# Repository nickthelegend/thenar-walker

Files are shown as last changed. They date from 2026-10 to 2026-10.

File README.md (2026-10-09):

# Thenar Walker — RoboReach 2026-27 robot

A 12 V four-wheel drive base for the **[thenar-arms](https://github.com/nickthelegend/thenar-arms)
MG996R follower arm**, built for [Techfest IIT Bombay RoboReach](https://techfest.org/competitions/roboreach).
The arm is unchanged; it is driven wirelessly by the thenar-arms **encoder leader** plus a joystick.
Everything is native SolidWorks 2026, generated by scripts so it can be rebuilt after any change.

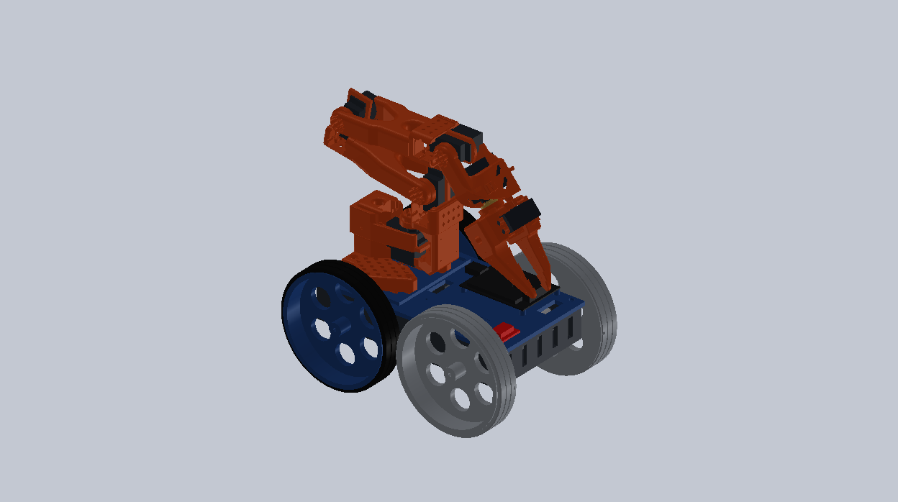
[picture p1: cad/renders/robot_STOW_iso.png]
Robot in the start pose


| | |
|---|---|
| Start size (STOW) | **293.7 × 196.0 × 292.9 mm** (rule 300 × 200 × 300) |
| Ground clearance | **57 mm** (rule ≥ 50) |
| Object centre at REACH_450 | **449.6 mm** in SolidWorks (rule: object centred at 450) |
| Mass | 2.37 kg (CAD) |
| Drive | 4 × 25GA-370 **12 V 60 RPM** (103:1), Ø140 printed wheels (one-piece PETG front, TPU-tyred rear), skid steer, ~0.34 m/s |
| Power | 3S LiPo 2200 mAh (12.6 V max, rule ≤ 24 V), 15 A fuse, 30 A kill switch |
| Link | ESP32 Wi-Fi AP `<TeamName>_TF`, HMAC-SHA256 signed commands, disconnect HOLD |

### Current build (October 2026) — what the team is actually building

The parts bought locally differ from the original design above, and the printable files follow the real parts:

| | |
|---|---|
| Motors | 4 × 370 plastic-gearbox 12 V ~100 RPM (gearbox Ø37.5, M8 × 13 collar + 13 mm nut, Ø6 round shaft). Bottle test passed (≥ ~5.2 kg·cm); simulated at 100 rpm: passes from 4.9 kg·cm |
| Chassis tub | **tub v2** — `cad/tools/tub_v2.py` (mesh CAD, 11/11 fit checks in `cad/evidence/tub_v2_checks.json`): M8 collar through 13 mm wall pads, nut pockets, walls to 100 mm, engraved **THENAR.IO** / **THENARLABS**. Ground clearance 51.25 mm, 294 × 196 mm |
| Deck | 3 mm wooden board cut to 250 × 138 — template `docs/wood_deck/` |
| Motor driver | Cytron **MDD10A** (one board, PWM + DIR), on the deck top |
| Wheels | 6 mm-bore versions (plate 4b), flat TPU tyre strips (plates 5F / 5G) |
| Assembly film | **[Watch / download the 4-minute assembly film](https://github.com/nickthelegend/thenar-walker/releases/tag/v1)** — every part and every connection, built from this CAD (`videos/thenar-assembly`) |

The SolidWorks assembly and `docs/VERIFICATION.md` still show the original 25 mm-motor tub; resync them when SolidWorks is available.

Full measured results: **[docs/VERIFICATION.md](docs/VERIFICATION.md)** (SolidWorks) and
**[docs/SIMULATION.md](docs/SIMULATION.md)** (physics: it drives the course and picks things up).

### It runs the course (MuJoCo physics + the real firmware logic in the loop)

| Scenario | Result |
|---|---|
| A — pick 50 mm cube → 15° ramp → bridge → ramp down → 4 speed breakers → place in the 80 mm square | **PASS 7/7** · [video](sim/out/mission_A.mp4) |
| B — same, with a 1.5 s Wi-Fi drop on the bridge + 75 forged/replayed packets | **PASS 12/12** — stops, arm freezes, gripper holds, attacks rejected · [video](sim/out/mission_B.mp4) |
| C — Downy: 60 mm cube off the 400 mm pole, arc turns like a driver, place in its square | **PASS 5/5** · [video](sim/out/mission_C.mp4) · [spin-in-place version](sim/out/mission_C_spin.mp4) |

| | |
|---|---|
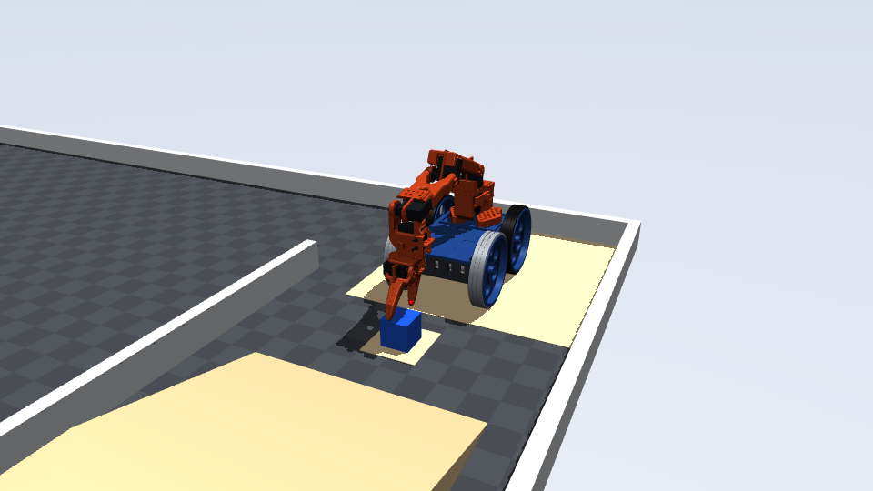
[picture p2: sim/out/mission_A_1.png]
pick
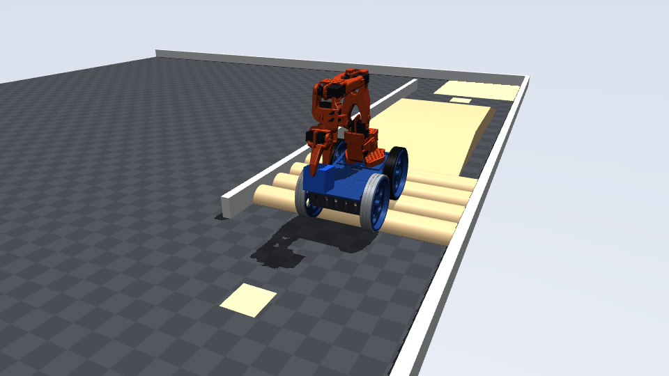
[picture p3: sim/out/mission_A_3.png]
|  |  |

## Contents

| Path | What |
|---|---|
| `cad/assemblies/Thenar_Walker.SLDASM` | Robot. Configurations **STOW**, HOME, REACH_450, PICK_FLOOR, DRIVE_ONLY |
| `cad/arena/RoboReach_Arena.SLDASM` | 3 × 3 m arena with all game objects, robot parked at the start |
| `cad/arena/Terrain_Check.SLDASM` | Robot on the ramp / bridge / speed breakers (last checked pose) |
| `cad/parts/` | Robot parts (RR-xx printed, P-xx purchased envelopes) |
| `cad/print/` | **Ready Bambu P1S plates** (5 × 3MF, no supports) — see [cad/print/PRINT.md](cad/print/PRINT.md) |
| `cad/stl/` | Single-part STLs |
| `cad/vendor/thenar-arms/` | thenar-arms follower master + parts (Apache-2.0, SO-ARM100 derived) with the four pose configurations added |
| `cad/tools/` | Python (pywin32) scripts that build and verify everything in SolidWorks |
| `analysis/` | URDF kinematics, collision-aware stow search, gripper opening, drive sizing |
| `sim/` | MuJoCo model of robot + arena, firmware-in-the-loop bridge, mission scenarios, videos (`sim/out/`) |
| `firmware/` | Robot + controller ESP32 sketches, shared `ThenarLink` library, host unit tests |
| `mobile/` | **Thenar Remote** Expo app (Android): drive + arm + Bluetooth game controller over the robot Wi-Fi — see [mobile/README.md](mobile/README.md) |
| `docs/calibrator/` | Browser arm calibrator (Web Serial) |
| `docs/` | [BOM](docs/BOM.md) · [Wiring](docs/WIRING.md) · [Build guide](docs/ASSEMBLY.md) · [Design notes](docs/DESIGN.md) · [Verification](docs/VERIFICATION.md) · [Simulation](docs/SIMULATION.md) |

| | |
|---|---|
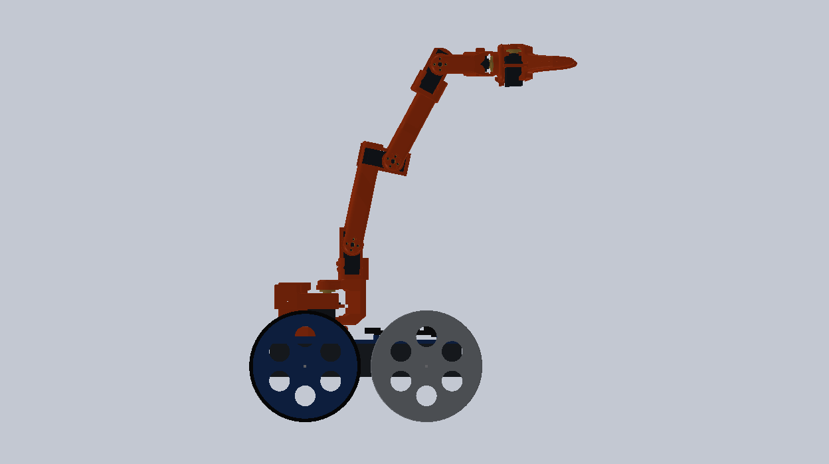
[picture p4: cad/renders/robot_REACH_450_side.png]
reach
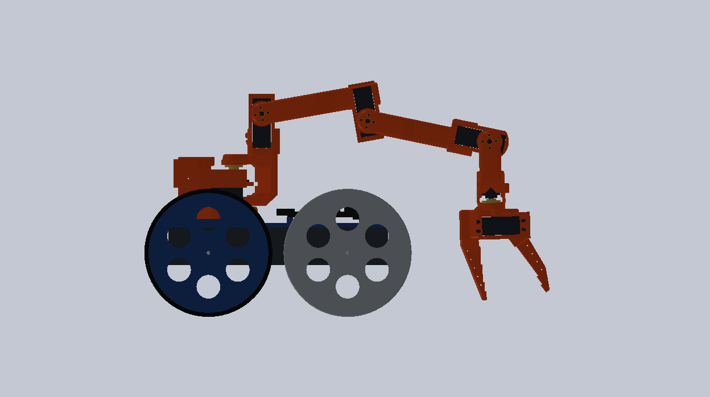
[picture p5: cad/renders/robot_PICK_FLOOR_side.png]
floor pick
|  |  |
| REACH_450 — object centred at 449.6 mm | PICK_FLOOR — 50 mm cube on the floor |
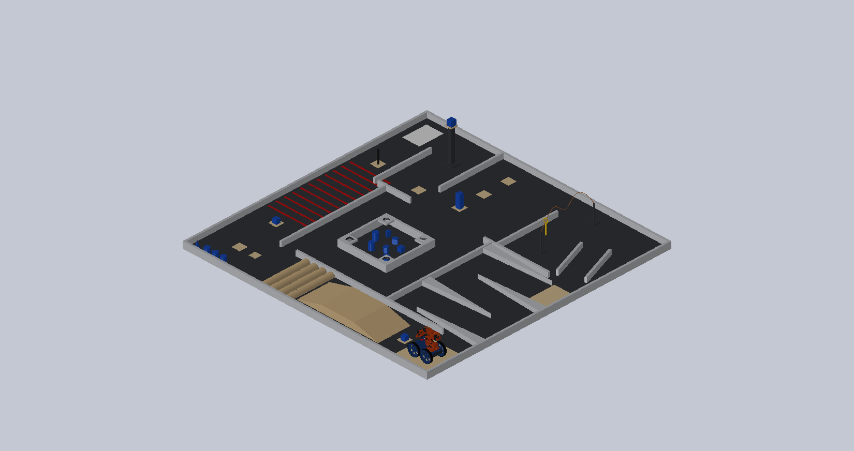
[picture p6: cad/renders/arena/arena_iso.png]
arena
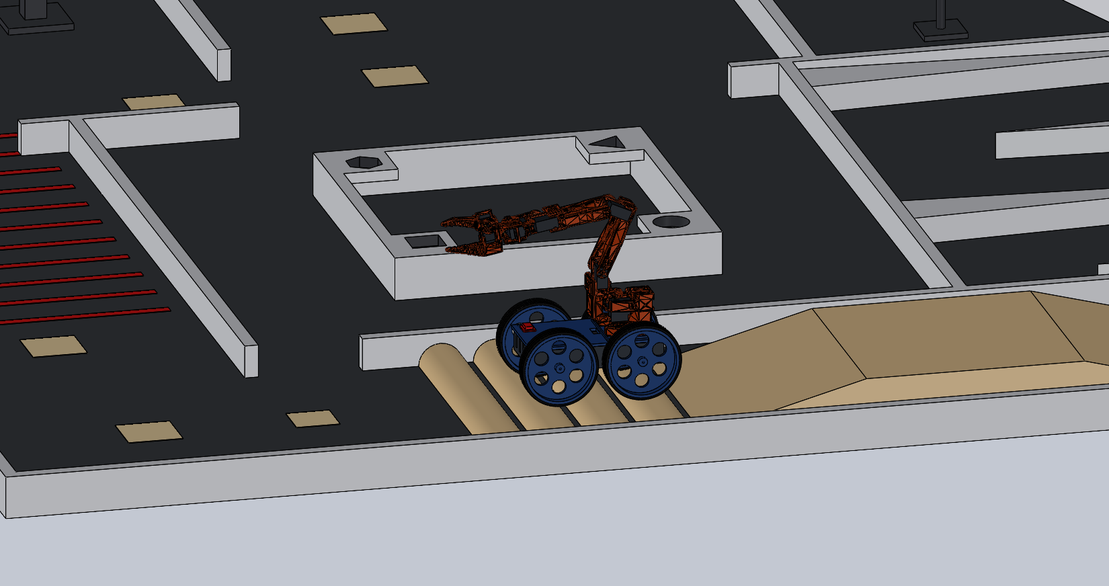
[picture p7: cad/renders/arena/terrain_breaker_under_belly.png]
|  |  |
| Arena (rulebook layout, ±10 %) | Over the 40 mm speed breakers |

## Rebuild / re-verify (SolidWorks 2026 must be running)

```
python cad/tools/build_parts.py          # all parts + STL
python cad/tools/make_plates.py          # P1S print plates (cad/print)
python cad/tools/prepare_arm.py          # arm pose configurations, cross-checked vs URDF
python cad/tools/build_robot.py          # robot assembly
python cad/tools/verify_robot.py         # rule checks (start box, clearance, reach, interference, stability)
python cad/tools/build_arena.py          # arena parts
python cad/tools/build_arena_asm.py      # arena assembly + terrain interference checks
python cad/tools/render_robot.py         # renders
python cad/tools/make_report.py          # docs/VERIFICATION.md
```

The scripts only open and close their own documents; other SolidWorks work stays open.
Python: `pywin32 numpy trimesh scipy python-fcl rtree`.

## Simulation

```
python sim/build_model.py            # MuJoCo model from the CAD numbers
python sim/run_mission.py A          # also B, C   (add --novideo to skip rendering)
python sim/turn_study.py             # skid-steer turning study (tyres / motors / spin vs arc)
python sim/make_sim_report.py        # docs/SIMULATION.md
```
Needs `mujoco imageio imageio-ffmpeg` and `sim/fw_bridge.exe` (build: `g++ -std=gnu++14 -O2 -static -o sim/fw_bridge.exe sim/fw_bridge.cpp`).

## Firmware

```
python firmware/tools/new_key.py "Your Team Name"
powershell -File firmware/tests/run_tests.ps1          # 39 host checks: SHA-256/HMAC, auth, replay, failsafe, turning
powershell -File firmware/tools/compile_firmware.ps1   # both ESP32 sketches
```

## Status

CAD, kinematics, collisions, obstacle clearance, the full course in physics simulation and the firmware
logic are verified in software. Nothing has been built or powered yet: check purchased parts against the
CAD, measure real tyre/gripper friction, calibrate the servos, and run the failsafe test in
`docs/ASSEMBLY.md` before the event.

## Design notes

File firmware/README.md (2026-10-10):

# Firmware

| Sketch | Board | Role |
|---|---|---|
| `thenar_walker_bot/` | ESP32 on the robot | Wi-Fi AP `<Team>_TF`, 4 × 12 V motors (1 × Cytron MDD10A, PWM + DIR), 6 × MG996R (PCA9685), failsafe |
| `thenar_phone/` | ESP32-S3 on the robot | **Phone control**: Wi-Fi AP `<Team>_TF`, page at http://192.168.4.1, WebSocket for low latency, calibrator over USB |
| `arm_calibration/` | ESP32-S3 on the robot | Serial bridge for the browser arm calibrator (`docs/calibrator/`), saves the calibration to NVS |
| `thenar_walker_controller/` | ESP32 in the thenar-arms L1 leader | Reads the 6 AS5600 joints + joystick, sends signed commands at 50 Hz |
| `libraries/ThenarLink/` | both + host tests | SHA-256/HMAC, packet format, replay gate, robot state machine, drive mixing |

Everything safety-relevant is in `libraries/ThenarLink/src/tw_robot.h` and is unit-tested on the PC
(`tests/run_tests.ps1`, uses PlatformIO's bundled MinGW g++). The sketches are thin hardware glue.

States: **DISARMED** (boot, servo PWM off) → **ACTIVE** (leader within 6° of STOW + ENABLE) ⇄
**HOLD** (link silent 250 ms / ENABLE off / bad target / encoder fault: wheels 0, arm frozen,
servo PWM kept on so the gripper holds). HOLD → ACTIVE only on a new authenticated command, with
a 45°/s catch-up limit for 1.5 s.

Driving: throttle is scaled 35/65/100 % by the SPEED button; turning in place uses its own 50/75/100 %
scale with a 35 % breakaway floor (`TURN_SCALE`, `SPIN_MIN`) — tuned for PETG front / TPU rear tyres
(sim/turn_study.py).

Credentials: `python tools/new_key.py "Team Name"` writes `libraries/ThenarLink/src/team_config.h`
(git-ignored). Flash both boards after generating it. The example config compiles with a warning
so you notice.

Servo calibration values live in `thenar_walker_bot/calibration.h` (same meaning as thenar-arms).
Until `FOLLOWER_CALIBRATED = true` the arm stays unpowered while the wheels work.

## Phone control (`thenar_phone`) — the way to drive the robot

The robot is a Wi-Fi hotspot `<Team>_TF`. Join it with the phone (turn mobile data off), open **http://192.168.4.1**:
joystick for the wheels, Slow/Mid/Fast, STOP, and per joint a slider, hold-to-move − / + buttons and ON/OFF.

Low latency: after the page loads, everything goes over one WebSocket (port 81) that stays open. A touch is sent the
moment it happens (once per screen frame at most), Nagle is off on both ends, the ESP32's Wi-Fi power save is off,
and the control loop runs at 100 Hz. The top bar shows the measured round trip in ms.

Safety: the phone sends at least every 40 ms; 300 ms of silence (tab closed, screen off, Wi-Fi lost) stops the wheels
and the hold buttons, and the arm holds where it is. Calibration: `docs/calibrator` talks to this same firmware over USB.

```
arduino-cli compile --fqbn esp32:esp32:esp32s3 --libraries firmware/libraries -u -p COM5 firmware/thenar_phone
```

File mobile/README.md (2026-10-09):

# Thenar Remote (Expo app)

Android app that drives the Thenar Walker: wheels, the 6-joint arm, and a Bluetooth game controller paired to the
phone. It talks to the robot firmware [`firmware/thenar_phone`](../firmware/thenar_phone) over the robot's own Wi-Fi
(`ThenarWalker_TF`, WPA2) at `http://192.168.4.1`.

## What it does that the robot's web page can't
- **Reads the game controller natively.** Any controller Android accepts (Switch-style, Xbox, PS, 8BitDo...) — no
  Chrome flag, no BLE limit. Buttons are consumed, so B doesn't act as Back.
- **Joins and pins the robot Wi-Fi.** Android normally sends traffic over mobile data when the Wi-Fi has no internet.
  The app binds itself to the robot network (⚙ → *Join robot Wi-Fi* asks Android once, Android 10+).
- Keeps the screen on, remembers the Wi-Fi password in the phone's secure storage.

## Controls
Screen: joystick (let go = stop), Slow/Mid/Fast, STOP, a slider + ±1/±5° + ON/OFF per joint, gripper open/close.

| Controller | Does |
|---|---|
| Left stick | drive |
| Right stick | J1 base pan (x), J2 shoulder (y) |
| D-pad ↑↓ / ←→ | J3 elbow / J5 wrist roll |
| Y / A | J4 wrist flex up / down |
| L2 / R2 | gripper open / close |
| L1 / R1 | speed down / up |
| **B** | **STOP** (wheels stay stopped until the stick is centred) |
| X | precision arm (20°/s instead of 60°/s) |
| hold START 1 s | arm ON — every calibrated joint (support the arm: joints jump to their target) |
| hold SELECT 1 s | arm limp |

Safety lives in the robot, not the phone: app silent for 0.5 s → wheels stop and the arm holds; the robot clamps every
angle to the calibrated safe ends; uncalibrated joints can't be switched on; the KCD4 kill switch cuts power.

## Install
Copy `Thenar_Remote.apk` to the phone and open it (allow "install unknown apps" for your file manager once).
Or with USB debugging: `adb install -r Thenar_Remote.apk`.

## Develop
```
npm install
npm test                 # end-to-end: app logic + gamepad mapping against a robot simulator (test/mock_robot.py)
npm run typecheck && npx expo lint
npm run mock             # robot simulator on 127.0.0.1:8793
npx expo start --web     # web build; ⚙ → robot address 127.0.0.1:8793 to drive the simulator
```
Build the APK (needs JDK 17 + Android SDK; the native module means Expo Go can't run it):
```
npx expo prebuild -p android
cd android && gradlew assembleRelease -PreactNativeArchitectures=arm64-v8a
# -> android/app/build/outputs/apk/release/app-release.apk
```

## Layout
- `App.tsx` — the screen
- `src/robot.ts` — robot link (protocol, 10 Hz exchange, merge with the robot's own state)
- `src/pad.ts` — controller layout (same as the firmware's Bluepad32 mapping)
- `modules/thenar-native` — local Expo module (Kotlin): gamepad events + Wi-Fi binding; web fallback uses the
  browser Gamepad API
- `test/` — `mock_robot.py` (firmware rules: slew, clamps, STOP latch, 0.5 s failsafe) and `e2e.test.ts`

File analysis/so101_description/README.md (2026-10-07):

# SO101 MG996R R3 description

Engineering prototype, not physically tested or payload rated. Generated from the checked SolidWorks reconstruction and measured component transforms.

Run `colcon build --packages-select so101_description`, source the install setup, then `ros2 launch so101_description display.launch.py` on a ROS 2 installation. ROS 2 GUI/build validation is not available in this Windows task environment; standalone Xacro/XML/kinematic validation is separate.

Six revolute joints include the directly driven moving jaw. The base frame retains the source convention. Add a +0.0024 m world-Z placement to match the SolidWorks tabletop scene. Mesh coordinates and URDF origins are metres.

No physical inertial guesses are included. Effort=0 deliberately grants no effort authority; it is not a servo rating. Velocity=10 deg/s is the existing firmware command slew ceiling. This geometry package does not provide a hardware driver, measured feedback, payload rating or physical-dynamics validation.

The servo collision envelope uses its exact source boxes and cylinders. Other collision meshes preserve the CAD solids. No convex print proxy has been accepted; do not let a physics importer silently replace each concave link with one convex hull. Shaft/horn spline engagement is intentional in the source. J2 and J3 maximum-at-other-joints-zero poses penetrate the tabletop.

Original project asset licensing still applies; no new license rights are asserted by this generated package.

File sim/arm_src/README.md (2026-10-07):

# MuJoCo handoff: kinematics checked, physical simulation blocked

`so101_import_test.urdf` was loaded in MuJoCo 3.14.0 and all 28 canonical link-pose comparisons passed. The importer silently inferred masses; these were rejected as physical robot properties. No dynamics steps were accepted or reported as physical verification.

`so101.xml` preserves the six-joint structural tree and visuals. It deliberately sets `inertiafromgeom="false"` and contains no fabricated inertials. MuJoCo must reject loading it until measured/supported link mass, COM and inertia are entered. Visual geoms have contacts disabled; validated convex contact proxies remain outstanding. This file is a structural template, not a runnable physical model.

The exact CAD collision meshes and raw intentional shaft/horn overlaps are retained in the ROS package. A 0.1 mm convex decomposition trial became impractically fragmented and was abandoned without accepting geometry. Do not replace each concave print with one convex hull. Damping, friction, armature, contact properties and actuator dynamics are unknown; future values must be separately labelled tuning assumptions.

Run `../../solidworks/tools/test_mujoco_urdf_import.py` from the project Python environment for the reproducible forward-kinematic inspection. Evidence: `../../verification/mujoco_urdf_import.json`.

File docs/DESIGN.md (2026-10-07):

# Design notes — Thenar Walker

A 12 V four-wheel skid-steer base that carries the **thenar-arms MG996R follower R3** unchanged,
teleoperated by the **thenar-arms L1 encoder leader** plus a thumb joystick, for Techfest 2026-27
RoboReach. Every number below is produced by a script in this repo; `docs/VERIFICATION.md` holds the
measured results.

## Rules that set the geometry

| Rule (RoboReach PS) | Consequence |
|---|---|
| Fits 300 L × 200 W × 300 H at the start | Arm must fold; base ≤ 300 × 200 including wheels |
| Arm grasps an object centred at 450 mm with the bot on the ground | Arm base height + reach |
| Ground clearance ≥ 50 mm (lowest point to ground) | Big wheels; motors on the axle line stay above 50 mm |
| Wheels in continuous contact | No legs/tracks over obstacles; Ø140 wheels roll over 40 mm breakers |
| ≤ 24 V, on-board battery, secured battery, kill switch | 3S LiPo (12.6 V max), printed battery cage, 30 A rocker in series |
| Wi-Fi/BT, SSID `TeamName_TF`, authentication, failsafe on disconnect | ESP32 AP + HMAC-signed UDP + HOLD state (see WIRING.md) |
| Mechanical gripper only | thenar-arms jaw gripper, no adhesive/magnet/suction |

## Layout (robot frame: X forward, Y left, Z up, origin on the ground at the chassis centre)

* **Wheels:** Ø140 (printed PETG hub + TPU tyre), 28 wide, centres at x = ±76, y = ±84.
  Overall 293.7 × 196 mm. A Ø140 wheel puts the axle at 70 mm, so a Ø25 JGA25 motor mounted
  coaxially bottoms out at 57.5 mm — above the 50 mm clearance rule without any belts or gears.
* **Motors:** gearbox faces screw to the inside of the tub side walls (U-slot pockets that open
  through the floor so the cans drop in). Left and right motors face each other with a 24 mm gap.
* **Tub (RR-01):** 240 × 138 mm, floor underside at **57 mm** = lowest point of the robot.
  Floor windows let the motor cans sit lower than the floor top.
* **Deck (RR-02):** top at **103 mm**. Electronics sit on the tub floor in one layer
  (battery cage on the left half; 6 V buck and PCA9685 on the right half; 5 V buck
  in the rear end bay; ESP32 hung under the deck above the 6 V buck). The Cytron MDD10A motor
  driver (84.5 × 62 mm, too big for the floor) sits on 4 bosses on the deck top, front-left, outside
  the stowed arm's path, with a wire slot in front of its terminals.
* **Arm:** base bolted to the deck at x = −87 through four of its own vent slots (no change to
  the thenar-arms parts), inside a 4 mm locating fence.

### Why the deck is so low (the 300 mm start height)

The first layout put the deck at 135 mm with an electronics tray. SolidWorks interference
detection then showed the folded arm colliding with itself (up to 9.6 cm³). A collision-aware
search over the arm's joint limits (`analysis/stow_search*.py`, python-fcl on the URDF meshes,
servo-horn spline overlap allowed) proved the lowest collision-free fold inside the ±80° software
limits is 187.5 mm tall above the arm's base frame (about 190 mm above the base underside). With a 135 mm deck that is 325 mm — over the rule. So the deck
came down to 103 mm and the electronics moved to the floor:

* **STOW pose:** pan 0, lift −80, elbow 80, wrist flex 50, wrist roll 85, gripper 0.
  Robot = 293.7 × 196 × 292.9 mm (6 / 4 / 7 mm margin), no self- or chassis collision.
  Wrist flex 45–55 are all clear, so ±5° of servo error is tolerated.
* The thenar-arms joint limits were **not** changed.

## Arm poses on the base (all collision-checked, then verified in SolidWorks)

The URDF `gripper_frame_link` ("tool") sits on the **fixed finger**, not between the jaws: a held
50 mm object is centred 26.5 mm from it along the closing axis. All grasp heights below are that true
object centre (`analysis/poses3.py`); an earlier draft quoted the tool point and was 25 mm off.

| Pose | Joints (deg) | What it shows |
|---|---|---|
| STOW | 0, −80, 80, 50, 85, 0 | start box |
| HOME | 0, −25, 35, 0, 0, 20 | thenar-arms home; carrying pose |
| REACH_450 | −3.4, 12, −73.8, 61.3, −85, 35 | 50 mm object centred at 449.6 mm (SolidWorks), gripper horizontal, jaws closing sideways, 260 mm ahead of centre |
| PICK_FLOOR | 0, 80, −68.3, 76.7, 3.4, 35 | 50 mm floor cube (centre z 25.1 mm) 254 mm ahead of centre |

The 400 mm Downy pole, the ≤ 400 mm buzz wire and the 340 mm stacker tower are inside the workspace;
the simulation (docs/SIMULATION.md) actually takes the 60 mm cube off the 400 mm pole.

## Drive sizing (`analysis/drive_sizing.py`)

Mass 2.37 kg from the CAD, sized at 2.61 kg. On the 15° ramp with 0.5 m/s² launch:
force 9.2 N → 0.64 N·m at the wheels → **1.63 kg·cm per motor** with four driving,
**3.27 kg·cm** if a breaker lifts one axle. The motor to buy in India is the **25GA-370 12 V 60 RPM (103:1)**:
rated 2.7, stall 8.2 kg·cm → margins 1.6× rated (4WD) and 2.5× to stall (2 wheels). The 100 rpm version
(stall ~3.6 kg·cm) would stall on the ramp — don't substitute it. Speed ~0.34 m/s loaded. Firmware speed modes: 35 % precision / 65 % / 100 % for driving.

**Steering:** skid steer (tank / JCB style) — no steering servo or shaft. One Cytron MDD10A drives both left wheels on
channel 1 and both right wheels on channel 2; the ESP32 mixes the joystick (left = throttle − turn, right = throttle + turn).
Different side speeds curve the robot, opposite directions spin it on the spot.

**Turning:** wheelbase 152 ≈ track 168, so every turn scrubs tyres sideways. With TPU on all four
wheels the simulation showed no spin below ~55 % power and arc turns of only 2.8°/s (it reversed 2 m
while turning 26°) — this is why the first video's smooth spin looked wrong. Stronger, slower motors
barely help. Fix: **PETG (hard) tyres at the front, TPU at the rear** → spin 20/77/136°/s at 35/65/100 %,
arcs 14°/s, ramp and speed breakers still pass (PETG at the rear stalls on the breakers). Firmware gives
rotation its own 50/75/100 % scale with a 35 % breakaway floor.

## Stability

COG at 104–149 mm height depending on pose. Worst static margin is 19 mm (PICK_FLOOR on a 15°
descent); carrying the cube in HOME on the descent leaves 33 mm. Drive rule: **carry the cube in
HOME (arm tucked) over the ramp, bridge and breakers**, don't descend with the arm stretched out.
The firmware ramps acceleration (full speed in 0.4 s) but stops immediately.

## Obstacles (verified in SolidWorks on the arena's own geometry, and driven in MuJoCo)

Ramp 15° to 80 mm, 400 mm bridge, ramp down, then four R40 half-cylinder breakers at 100 mm pitch.
Nine solved poses (ramp foot, on ramp, crest, bridge, bridge exit, down-ramp foot, front wheels on
the first breaker, breaker under the belly, rear wheels on the last breaker): only the tyres
touch the obstacles. Breakover angle is 2·atan(57/76) ≈ 74°; the tub ends lie inside the wheel
silhouettes, so approach/departure angles are effectively 90°.

The diagonals corridor is 250 mm and the robot is 196 mm wide; it cannot spin on the spot inside it
(needs a 352 mm circle), so drive the corridor in arcs.

## Electronics and failsafe

ESP32 robot controller → PCA9685 (servos) + Cytron MDD10A (motors, on the deck top), powered from a 3S LiPo through a
15 A fuse and the kill switch. The controller is the leader ESP32. Link: WPA2 AP `<Team>_TF`,
one station, HMAC-SHA256 on every packet, random session id per pairing, monotonic sequence numbers.
HOLD on 250 ms of silence, operator disable, bad target or encoder fault: wheels 0, arm frozen,
gripper PWM kept on. The original thenar-arms follower turned servo outputs OFF on watchdog
timeout (OE high), which would drop the cube and break the RoboReach disconnect rule — this
firmware keeps them on and only freezes motion.

## Known limits / to measure on the real parts

* Motor shaft ≥ 10 mm and flat orientation; hub grub screw lands on the flat.
* Gripper does not fully close (19.7 mm at 0°): add TPU finger pads for the marker task.
* Board footprints and mounting holes are nominal — check before printing the tub.
* Arena positions are reconstructed from the rulebook renders; dimensions of the obstacles
  themselves follow the rulebook.

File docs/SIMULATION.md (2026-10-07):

# End-to-end simulation — Thenar Walker

Generated by `sim/make_sim_report.py`. Physics: MuJoCo 3.14, 1 ms steps. Control: the **real firmware logic** (`firmware/libraries/ThenarLink`: HMAC packet gate + `tw::Robot` state machine) compiled into `sim/fw_bridge.exe` and run every 10 ms. The operator (leader-arm angles + joystick) is scripted: it sees the scene like a person would and only sends what a person could send — nothing bypasses the firmware.

| Scenario | Result | Simulated time | Video |
|---|---|---|---|
| A: Main course — pickup → 15° ramp → bridge → ramp down → 4 speed breakers → touchdown | **PASS** (7/7) | 27.9 s | [mission_A.mp4](../sim/out/mission_A.mp4) |
| B: Same course + 1.5 s radio drop on the bridge while forged and replayed packets are sent | **PASS** (12/12) | 29.3 s | [mission_B.mp4](../sim/out/mission_B.mp4) |
| C: Downy — 60 mm cube off the 400 mm pole, reverse/forward arc turns, place in the target square | **PASS** (5/5) | 54.6 s | [mission_C.mp4](../sim/out/mission_C.mp4) |
| C_spin: Downy again, but turning by spinning in place instead of arcs | **PASS** (5/5) | 32.4 s | [mission_C_spin.mp4](../sim/out/mission_C_spin.mp4) |

## Scenario A — Main course — pickup → 15° ramp → bridge → ramp down → 4 speed breakers → touchdown

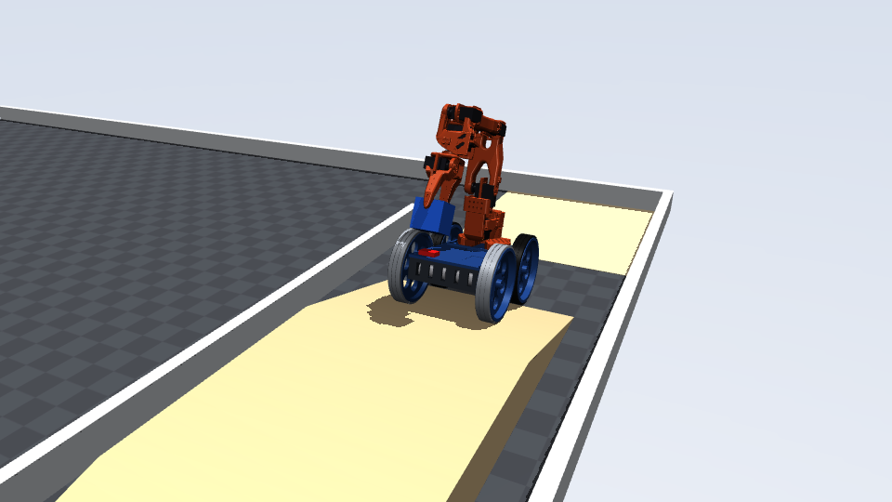
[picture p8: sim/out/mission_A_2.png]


| Result | Check | Measured |
|---|---|---|
| PASS | Robot never tips (|roll| < 25 deg, |pitch| < 25 deg) | max |pitch| 15.3 deg, max |roll| 0.1 deg |
| PASS | Chassis / motors never touch an obstacle (only tyres do) | no contacts |
| PASS | Pickup: cube lifted clear of the ground | max cube height 290 mm |
| PASS | Cube held by the gripper the whole way (no drop) | 1341 samples from pickup to touchdown, 0 with the cube > 20 mm from the grasp point |
| PASS | Climbed the 15 deg ramp and crossed the 400 mm bridge | max chassis lift 80.0 mm (bridge = 80) |
| PASS | Drove down and over all four 40 mm speed breakers | rear axle passed y = 0.597 m |
| PASS | Placed completely inside the 80 x 80 mm square | cube centre offset (+2.5, +13.1) mm, z 25.0 mm |

Events: 2.4 s approach_error_mm = 3.1891238748290585; 8.5 s cube50_in_hand_offset_mm = [-24.8, 0.0, 5.8]; 8.5 s cube50_lifted_to_mm = 101.9; 8.5 s ik_unreachable; 17.1 s place_align_error_mm = 15.798148342652695; 18.4 s cube50_in_hand_offset_mm = [-25.1, 0.0, 12.4]

## Scenario B — Same course + 1.5 s radio drop on the bridge while forged and replayed packets are sent

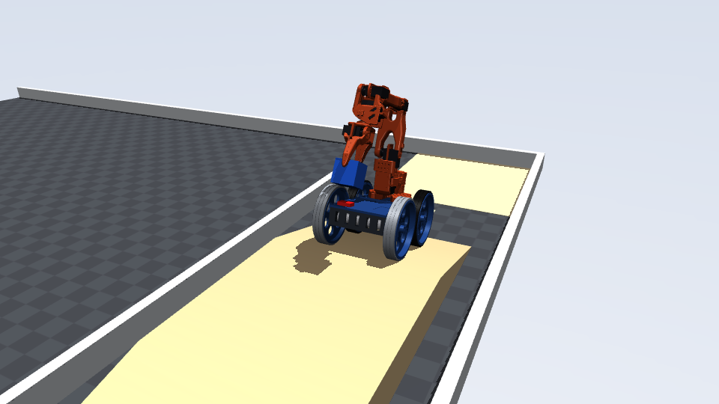
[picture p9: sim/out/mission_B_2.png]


| Result | Check | Measured |
|---|---|---|
| PASS | Robot never tips (|roll| < 25 deg, |pitch| < 25 deg) | max |pitch| 15.3 deg, max |roll| 0.1 deg |
| PASS | Chassis / motors never touch an obstacle (only tyres do) | no contacts |
| PASS | Pickup: cube lifted clear of the ground | max cube height 290 mm |
| PASS | Cube held by the gripper the whole way (no drop) | 1482 samples from pickup to touchdown, 0 with the cube > 20 mm from the grasp point |
| PASS | Climbed the 15 deg ramp and crossed the 400 mm bridge | max chassis lift 80.0 mm (bridge = 80) |
| PASS | Drove down and over all four 40 mm speed breakers | rear axle passed y = 0.597 m |
| PASS | Placed completely inside the 80 x 80 mm square | cube centre offset (+2.4, +12.5) mm, z 25.0 mm |
| PASS | Forged + replayed packets during the drop are all rejected | 75 attack packets, 0 accepted |
| PASS | Link lost -> firmware HOLD within 260 ms, wheel duty 0 | state during drop: [2] |
| PASS | Robot stops (speed < 2 cm/s by the end of the drop) | speed 0 mm/s at end, rolled 11 mm after HOLD |
| PASS | Arm motion ceases (joint drift < 2 deg during HOLD) | max joint drift 0.21 deg |
| PASS | Gripper keeps holding the cube through the drop | cube stayed in the jaws |

Events: 2.4 s approach_error_mm = 3.1891238748290585; 8.5 s cube50_in_hand_offset_mm = [-24.8, 0.0, 5.8]; 8.5 s cube50_lifted_to_mm = 101.9; 8.5 s ik_unreachable; 12.8 s RADIO DROP begins (robot on the bridge); 14.3 s radio restored; 18.5 s place_align_error_mm = 15.797412824933716; 19.8 s cube50_in_hand_offset_mm = [-25.1, 0.0, 12.5]

## Scenario C — Downy — 60 mm cube off the 400 mm pole, reverse/forward arc turns, place in the target square

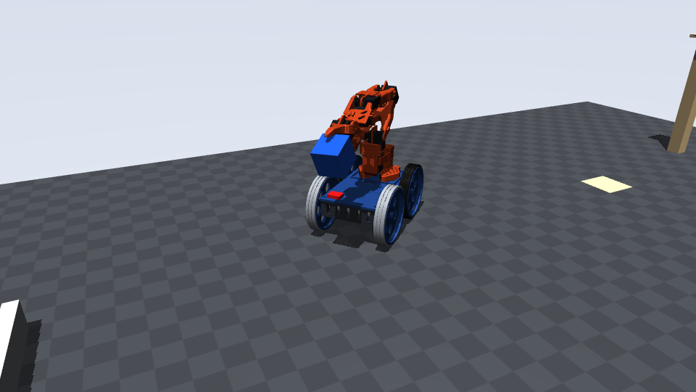
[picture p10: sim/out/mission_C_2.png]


| Result | Check | Measured |
|---|---|---|
| PASS | Robot never tips (|roll| < 25 deg, |pitch| < 25 deg) | max |pitch| 0.1 deg, max |roll| 0.0 deg |
| PASS | Chassis / motors never touch an obstacle (only tyres do) | no contacts |
| PASS | Downy: 60 mm cube taken off the 400 mm pole | max cube centre 539 mm |
| PASS | Turned to face the target square (final aim error < 3 deg) | {"style": "reverse arc + forward arc", "duration_s": 14.8, "rotation_travelled_deg": 284.4, "final_aim_error_deg": 0.05, "peak_motor_current_A_total": 2.27, "mean_motor_current_A_total": 1.02, "mean_battery_current_A_motors": 0.44, "time_above_80pct_stall_s": 0.0} |
| PASS | Placed completely inside the 100 x 100 mm square | cube centre offset (+3.2, -10.2) mm, z 30.0 mm |

Events: 2.4 s approach_error_mm = 3.193155147488469; 9.2 s cube60_lifted_off_pole_mm = 22.4; 17.4 s arc_turn (reverse) heading error deg = -2.97; 23.2 s arc_turn (forward) heading error deg = -2.98; 26.9 s turn_in_place_final_error_deg = 0.05; 26.9 s place_align_error_mm = 3.2568950317535816; 32.6 s cube60_in_hand_offset_mm = [-33.3, 7.8, 5.4]

## Scenario C_spin — Downy again, but turning by spinning in place instead of arcs

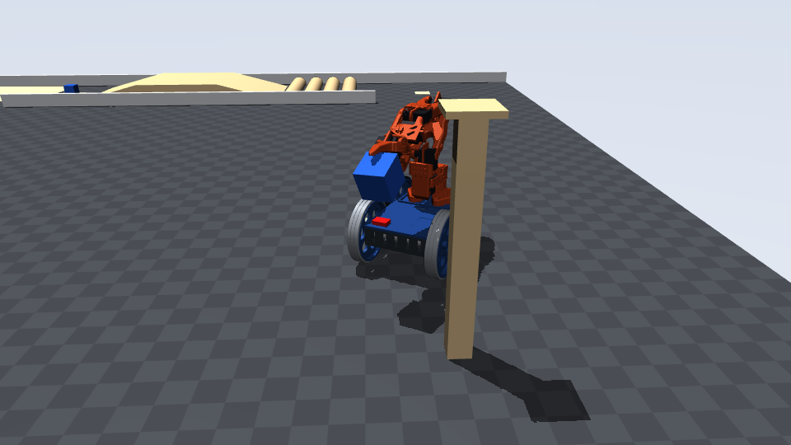
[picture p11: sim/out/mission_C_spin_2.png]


| Result | Check | Measured |
|---|---|---|
| PASS | Robot never tips (|roll| < 25 deg, |pitch| < 25 deg) | max |pitch| 0.1 deg, max |roll| 0.0 deg |
| PASS | Chassis / motors never touch an obstacle (only tyres do) | no contacts |
| PASS | Downy: 60 mm cube taken off the 400 mm pole | max cube centre 539 mm |
| PASS | Turned to face the target square (final aim error < 3 deg) | {"style": "spin in place", "duration_s": 3.8, "rotation_travelled_deg": 145.2, "final_aim_error_deg": -0.15, "peak_motor_current_A_total": 1.69, "mean_motor_current_A_total": 1.2, "mean_battery_current_A_motors": 0.57, "time_above_80pct_stall_s": 0.0} |
| PASS | Placed completely inside the 100 x 100 mm square | cube centre offset (-8.3, +6.9) mm, z 30.0 mm |

Events: 2.4 s approach_error_mm = 3.193155147488469; 9.2 s cube60_lifted_off_pole_mm = 22.4; 16.0 s turn_in_place_final_error_deg = -0.15; 16.0 s place_align_error_mm = 3.2811744713195923; 19.6 s cube60_in_hand_offset_mm = [-32.6, 7.9, 4.3]

## Turning study (`sim/turn_study.py`)

The robot is almost square (wheelbase 152 mm, track 168 mm), so every turn drags tyres sideways. With grippy TPU on all four wheels it could only spin above ~55 % power and **arc turns barely worked (2.8°/s)** — in an arc test it reversed 2 m and turned 26°. Stronger (slower) motors barely help. Hard PETG tyres at the **front** let the front slide while the TPU rear pushes: spin and arcs both work, it still climbs the ramp and crosses the speed breakers (scenarios A and B). PETG at the **rear** was also tried and gets stuck on the breakers.

| Variant | spin_35%_deg_s | spin_65%_deg_s | spin_100%_deg_s | arc_30/90%_deg_s | arc_speed_m_s | straight_100%_m_s | climbs_ramp_at_35% |
|---|---|---|---|---|---|---|---|
| JGA25 78:1 (6.2 kg.cm, 77 rpm), all TPU  [current] | 0.2 | 31.6 | 83.6 | 2.8 | 0.31 | 0.53 | True |
| JGA25 131:1 (~10 kg.cm, ~46 rpm), all TPU | 7.5 | 32.1 | 64.4 | 5.3 | 0.19 | 0.32 | True |
| JGA25 171:1 (~12 kg.cm, ~35 rpm), all TPU | 8.2 | 26.5 | 52.8 | 6.3 | 0.15 | 0.24 | True |
| JGA25 78:1, PETG front / TPU rear | 20.0 | 77.0 | 136.2 | 14.3 | 0.31 | 0.53 | True |

Firmware: rotation has its own scale (50/75/100 %) and a 35 % breakaway floor (`TURN_SCALE`, `SPIN_MIN` in `tw_robot.h`). Drive like a car where you can (arcs); spin on the spot only for small corrections or tight spots.

## Model inputs and assumptions

* Masses: SolidWorks volumes × PETG/TPU densities + datasheet masses; arm link COM/inertia integrated over the thenar-arms meshes. Robot 2.37 kg.
* Arm kinematics: thenar-arms `simulation/mujoco/so101.xml` (URDF-validated). Finger contacts: 3 boxes per finger fitted to the jaw meshes (gap is 4–16 mm tighter than the real jaws — conservative).
* Wheels: Ø140 cylinders; JGA25-370 78:1 torque–speed line (stall 6.2 kg·cm, 77 rpm free) × battery 11.6/12 V.
* Servos: MG996R as stall-limited position servos; firmware slew limit applied first.

| Assumption | Value |
|---|---|
| tyre_friction_TPU_on_ply | 0.9 |
| tyre_friction_PETG_on_ply | 0.35 |
| front_tyre_material | PETG |
| rear_tyre_material | TPU |
| finger_friction | 1.0 |
| object_friction_thermocol | 0.7 |
| cube50_mass_kg | 0.02 |
| cube60_mass_kg | 0.03 |
| servo_stall_Nm | 1.08 |
| servo_kp_Nm_per_rad | 30.0 |
| gripper_kp_Nm_per_rad | 3.0 |
| servo_armature | 0.004 |
| wheel_armature | 0.004 |
| motor | 25GA-370 / JGA25-370 12 V 103:1 (60 rpm free, rated 2.7 kg.cm @ 46 rpm, stall 8.2 kg.cm / 1.3 A) |
| motor_stall_Nm | 0.8041453 |
| motor_free_rad_s | 6.283185307179585 |
| battery_V_over_12 | 0.9666666666666667 |

## What the simulation does not prove

* Friction values are assumptions (TPU on plywood, thermocol on PETG). Test the real tyres on the ramp and the real gripper on a thermocol cube.
* Thermocol is modelled rigid; a real EPS cube dents under ~10 N — squeeze gently (gripper 15–20° on the leader).
* The scripted operator has perfect eyes and a steady hand. Practise the course: the human is the controller.
* Wi-Fi is modelled as packet delivery/loss only (no latency jitter, no interference).

## What-if: 25GA-370 **100 RPM** motors (the ones the team could buy locally)

`TW_MOTOR_RPM=100 TW_MOTOR_STALL_KGCM=<x> TW_TAG=... python sim/run_mission.py A|B|C` (baseline results untouched):

| Stall torque | A (ramp, bridge, breakers, place) | B (radio drop) | C (Downy, turn, place) |
|---|---|---|---|
| 3.6 kg·cm | FAIL — stuck on the speed breakers | — | — |
| 4.2 kg·cm | FAIL — speed breakers | — | — |
| 4.5 kg·cm | FAIL — speed breakers | — | — |
| **4.9 kg·cm** (same motor, 100 rpm gearing) | **ALL PASS** | **ALL PASS** | arcs at normal speed brush the corridor wall; **ALL PASS** with the arcs in precision mode, and with spin-in-place |

So the 100 rpm motor works only if it really makes ≥ ~4.9 kg·cm (bottle test: lift 750 ml at 7 cm), with
precision mode for manoeuvring near the poles.

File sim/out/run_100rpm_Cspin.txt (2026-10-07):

  t=  0.01s  phase engage       robot (+0.480, +0.800)  fw state 1
  t=  0.41s  phase unfold       robot (+0.480, +0.800)  fw state 1
  t=  2.43s  phase approach     robot (+0.480, +0.800)  fw state 1
  t=  5.38s  phase reach_450    robot (+0.849, +0.800)  fw state 1
  t=  6.00s  phase grip         robot (+0.848, +0.800)  fw state 1
  t=  6.80s  phase lift_off_pole robot (+0.848, +0.800)  fw state 1
  t=  7.24s  phase back_off     robot (+0.843, +0.800)  fw state 1
  t=  8.84s  phase carry        robot (+0.690, +0.800)  fw state 1
  t= 10.22s  phase turn         robot (+0.690, +0.800)  fw state 1
  t= 13.92s  phase align        robot (+0.587, +0.731)  fw state 1
  t= 16.33s  phase lower        robot (+0.738, +0.913)  fw state 1
  t= 22.39s  phase release      robot (+0.740, +0.916)  fw state 1
  t= 26.84s  phase retract      robot (+0.733, +0.906)  fw state 1
  t= 27.79s  phase done         robot (+0.733, +0.906)  fw state 1
PASS Robot never tips (|roll| < 25 deg, |pitch| < 25 deg) — max |pitch| 0.1 deg, max |roll| 0.0 deg
PASS Chassis / motors never touch an obstacle (only tyres do) — no contacts
PASS Downy: 60 mm cube taken off the 400 mm pole — max cube centre 536 mm
PASS Turned to face the target square (final aim error < 3 deg) — {"style": "spin in place", "duration_s": 3.7, "rotation_travelled_deg": 131.8, "final_aim_error_deg": -0.05, "peak_motor_current_A_total": 2.42, "mean_motor_current_A_total": 1.73, "mean_battery_current_A_motors": 0.83, "time_above_80pct_stall_s": 0.0}
PASS Placed completely inside the 100 x 100 mm square — cube centre offset (-7.2, +1.4) mm, z 30.0 mm
  event {'t': 2.42, 'event': 'approach_error_mm', 'value': np.float64(1.3378931360584767)}
  event {'t': 7.23, 'event': 'cube60_lifted_off_pole_mm', 'value': np.float64(23.4)}
  event {'t': 13.91, 'event': 'turn_in_place_final_error_deg', 'value': -0.05}
  event {'t': 13.91, 'event': 'place_align_error_mm', 'value': np.float64(1.4457437938438233)}
  event {'t': 16.32, 'event': 'cube60_in_hand_offset_mm', 'value': [-31.9, 8.7, 3.5]}
scenario C: ALL PASS in 28.8 s simulated

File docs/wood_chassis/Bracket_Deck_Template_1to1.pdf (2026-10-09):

DECK 250 × 138, top view, FRONT to the right. Blue bars = motor bracket face (under the deck). Drill B Ø3.4, C Ø3.4; cut K 22.2 × 30.2, S1/S2 12 × 30.

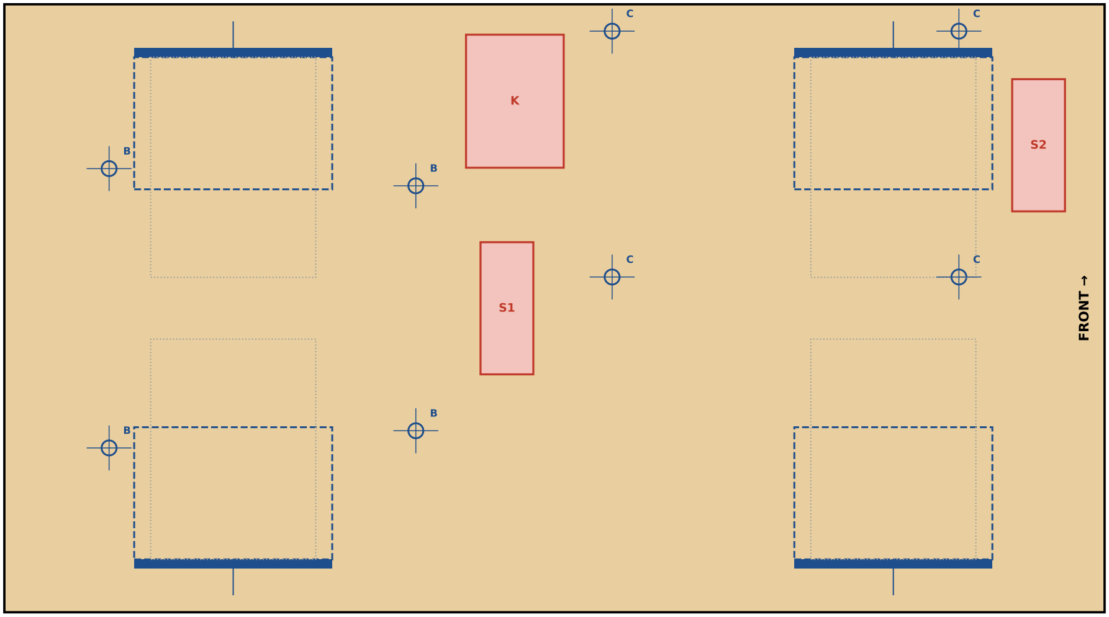
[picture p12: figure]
FRONT

must measure exactly 100 mm print at 100 % / "Actual size"

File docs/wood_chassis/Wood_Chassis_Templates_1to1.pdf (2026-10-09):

DECK 250 × 138 | top view, FRONT to the right. Tape on, drill at the crosses, cut the red windows.

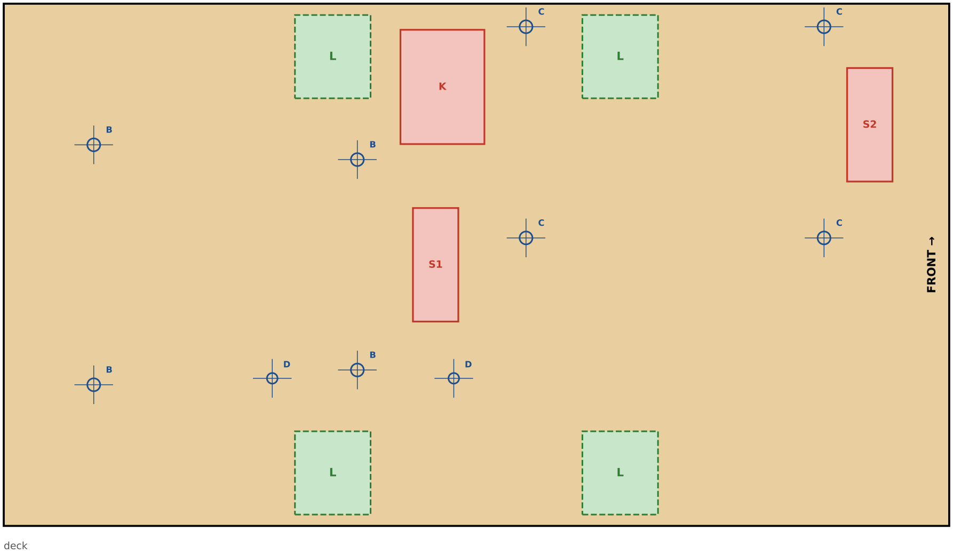
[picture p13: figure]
deck; FRONT

must measure exactly 100 mm | print at 100 % / "Actual size"

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

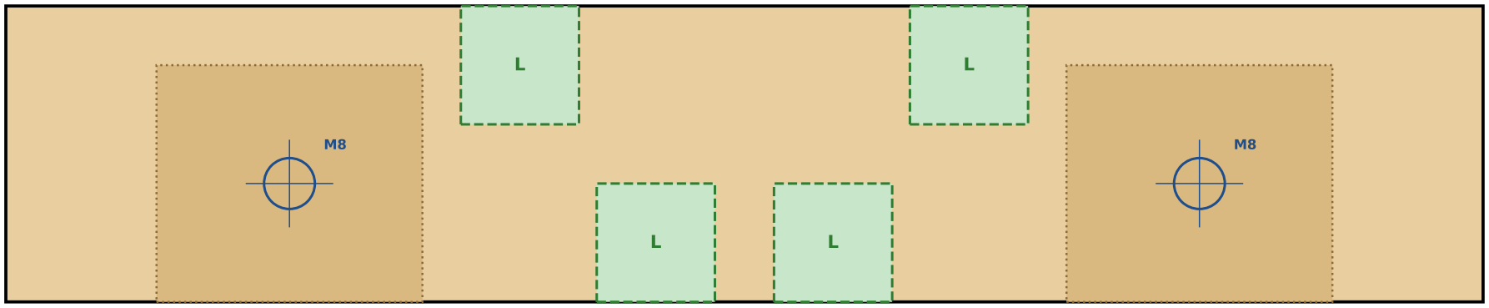
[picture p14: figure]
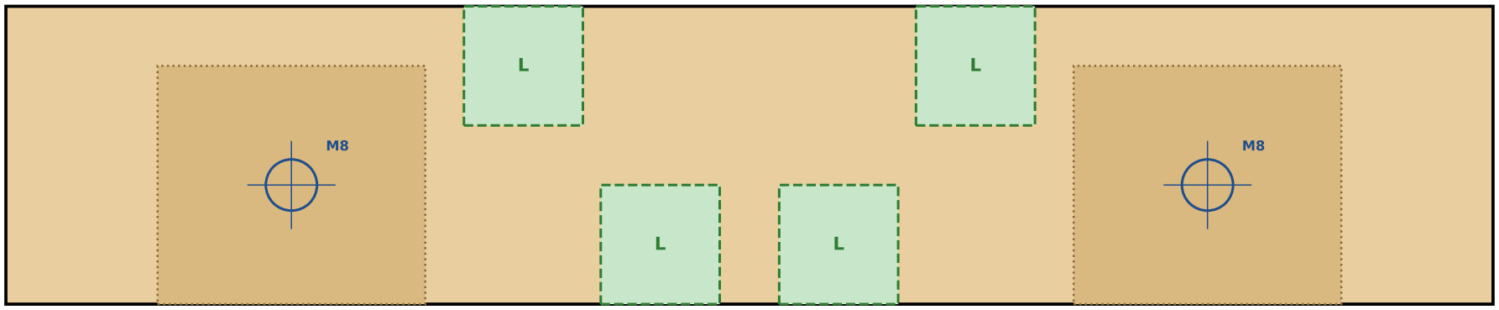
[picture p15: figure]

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

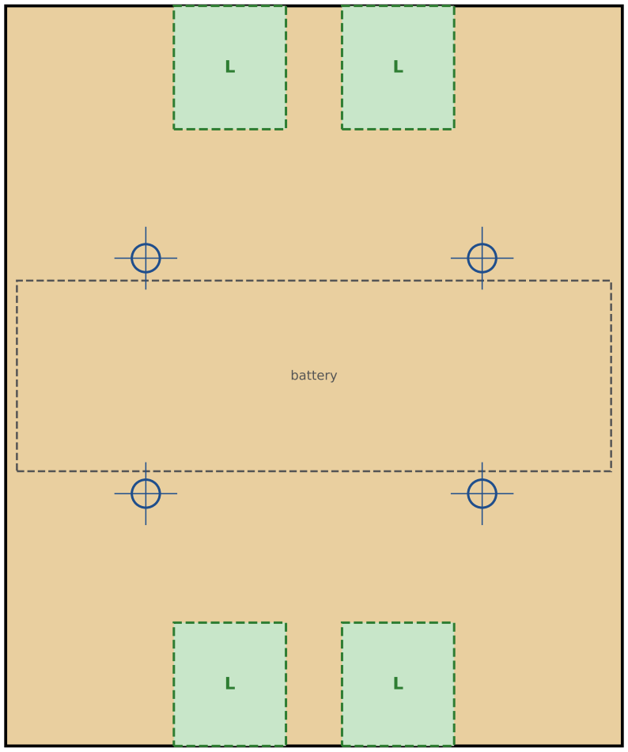
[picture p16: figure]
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

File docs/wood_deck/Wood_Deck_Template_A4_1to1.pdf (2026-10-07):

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

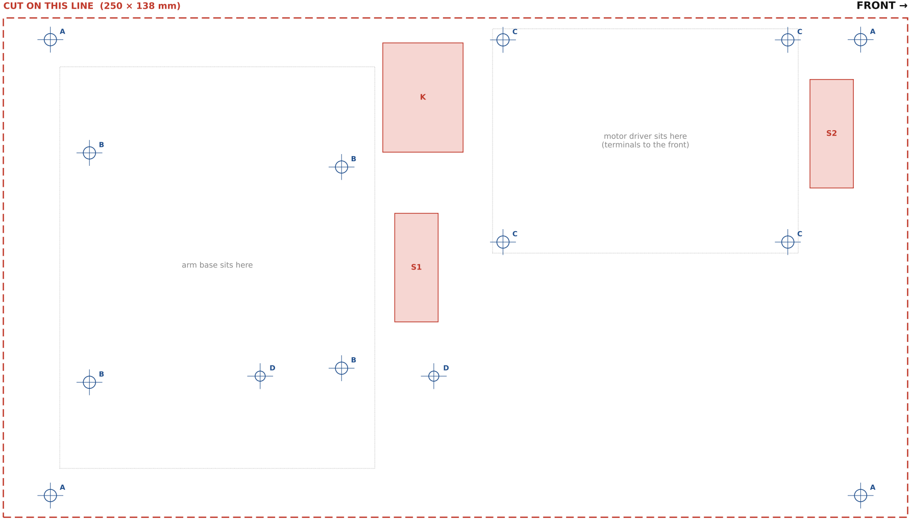
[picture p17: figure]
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

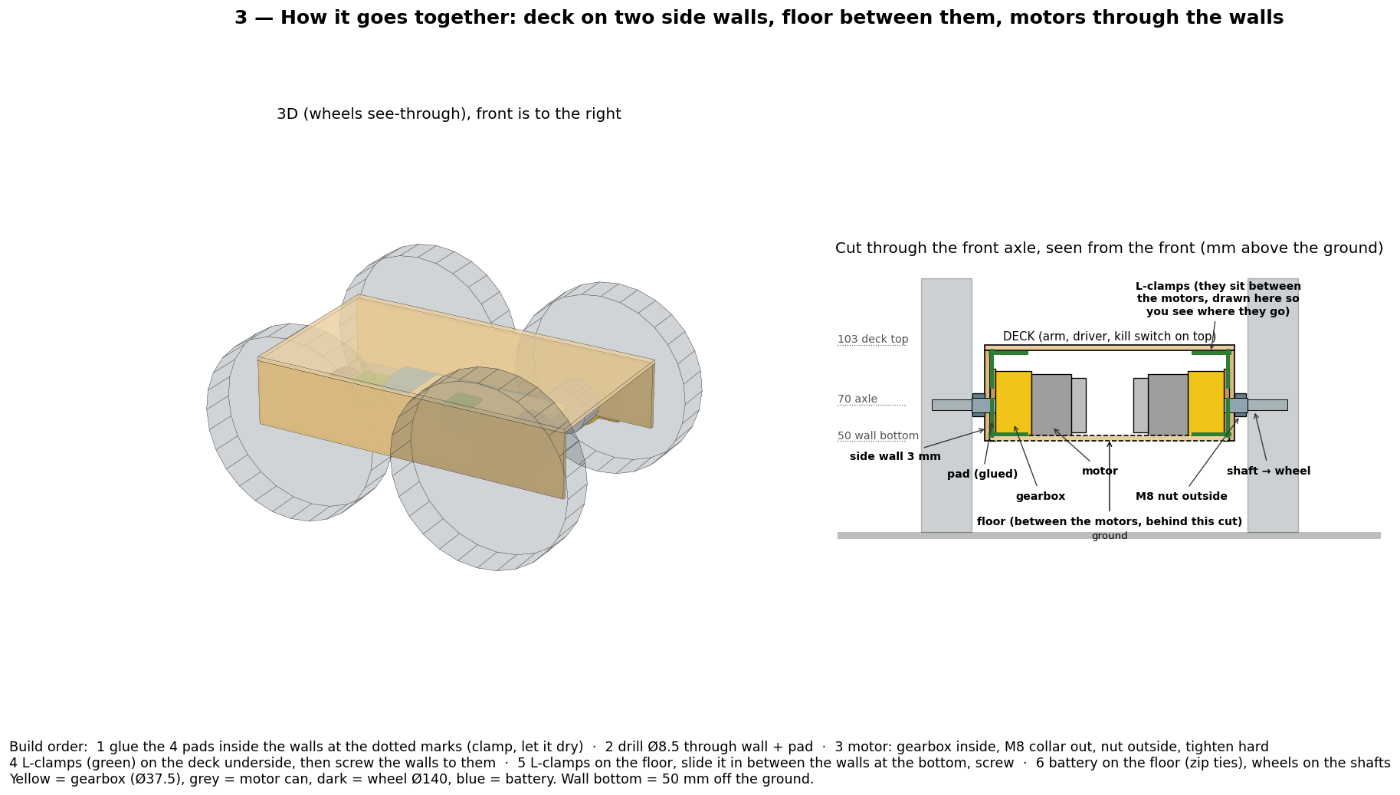
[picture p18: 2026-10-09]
docs/wood_chassis/3_How_It_Goes_Together.png

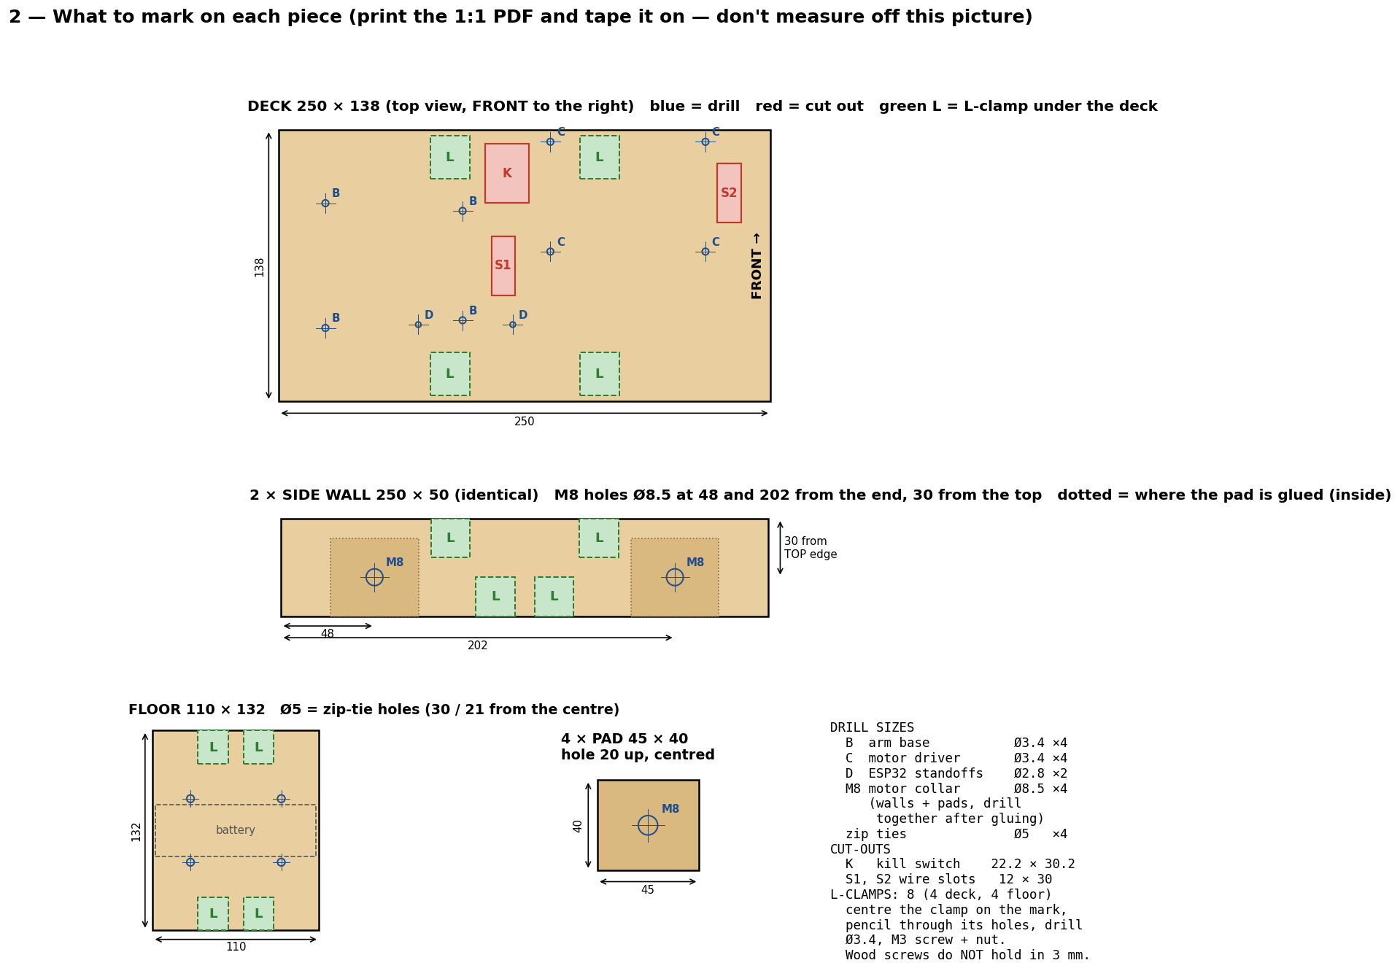
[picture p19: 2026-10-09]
docs/wood_chassis/2_Mark_Each_Piece.png

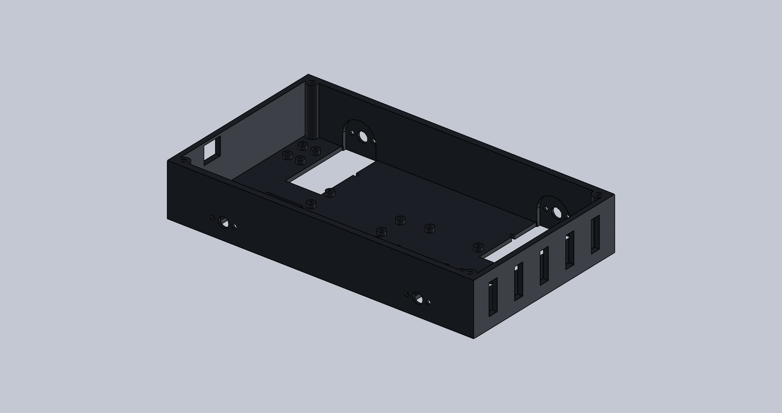
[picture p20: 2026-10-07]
cad/renders/parts/RR-01_Chassis_Tub.png

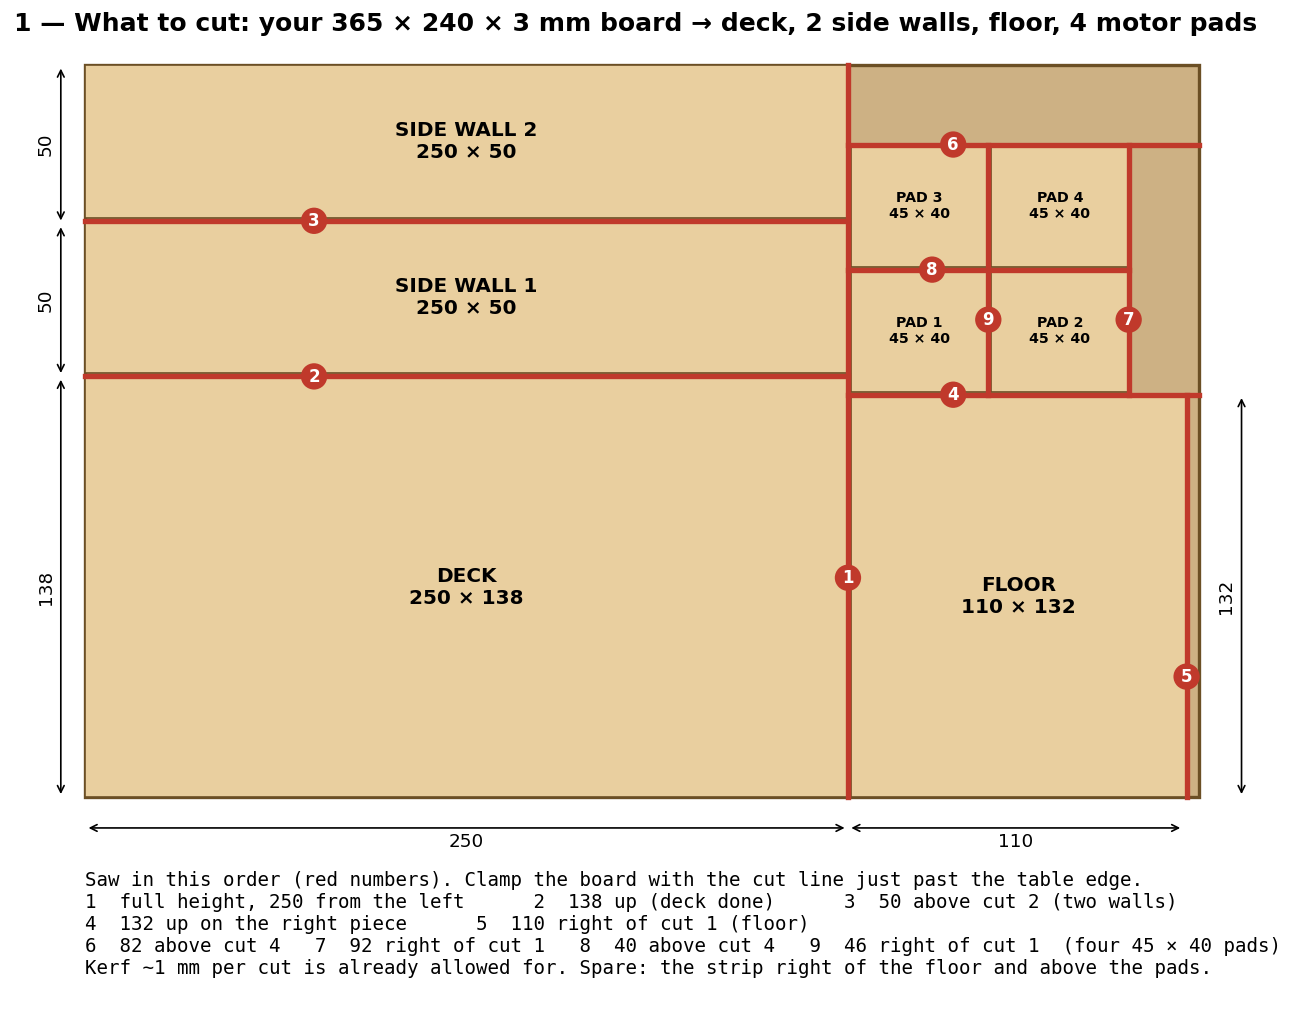
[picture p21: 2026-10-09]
docs/wood_chassis/1_Cut_Plan.png

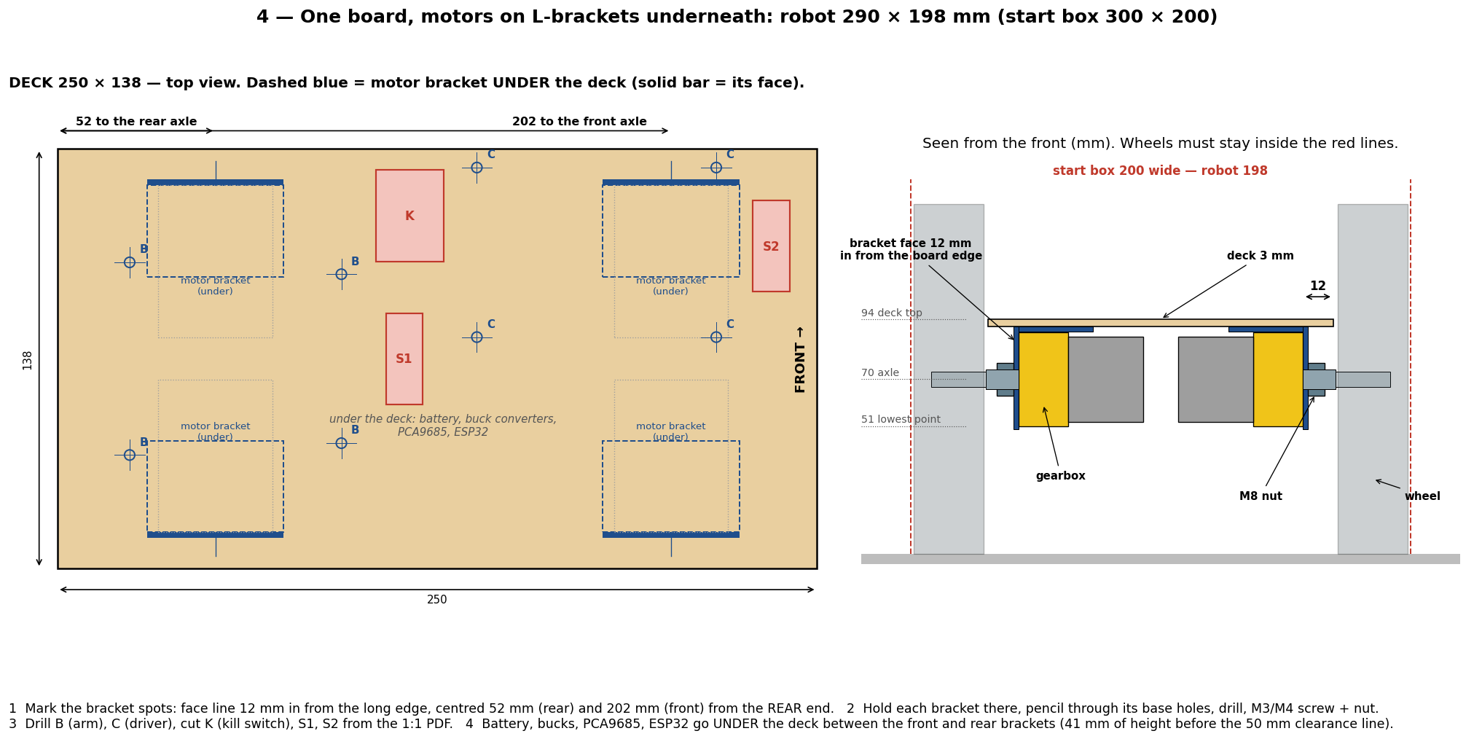
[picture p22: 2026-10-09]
docs/wood_chassis/4_Bracket_Deck.png

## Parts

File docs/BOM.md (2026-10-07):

# Bill of materials — Thenar Walker (RoboReach 2026-27)

Quantities are for **one robot + one controller**. Printed masses come from the SolidWorks volumes
(PETG at 1.27 g/cm³ × 0.55 effective fill for 4 walls + 30 % gyroid, TPU at 1.21 g/cm³ × 0.6).
Robot total from the CAD: **2.37 kg** (sized with +10 % → 2.61 kg).
Purchased dimensions are nominal envelopes — check your actual parts against the CAD before printing.

---

## 1. Moving parts

### 1a. Drive train — 4 identical wheel stations (skid steer, 12 V)

| # | Part | Qty | Spec / why | CAD |
|---|---|---:|---|---|
| D1 | **25GA-370 (= JGA25-370) 12 V 60 RPM gear motor, 103:1, 4 mm D-shaft, no encoder** — e.g. [The Engineer Store](https://www.theengineerstore.in/products/25ga-370-12v-60rpm-dc-gear-motor) (in stock when checked, ₹462); also listed by [Robu](https://robu.in/product/25ga-370-12v-60rpm-dc-gear-motor/), [Kitsguru](https://kitsguru.com/products/25ga370-dc-12v-60rpm-reduction-motor-high-torque), [Robotics DNA](https://roboticsdna.in/product/25ga-370-12v-60rpm-dc-gear-motor/), [Zbotic](https://zbotic.in/product/25ga-370-12v-60rpm-dc-gear-motor/) | 4 (+1 spare) | Rated 2.7 kg·cm @ 46 rpm, stall 8.2 kg·cm / 1.3 A. 15° ramp needs 1.63 kg·cm per motor (1.6× margin) and 3.27 kg·cm when only 2 wheels drive. Simulated end-to-end with these numbers (docs/SIMULATION.md). **Avoid the 100 RPM version** (stall ~3.6 kg·cm). Check the shaft is D-shaped (Robu's 9.4 mm shaft length is OK). **Listings disagree on torque** (Robu: stall 4 kg·cm; Kitsguru: 8.2) and the sim needs **≥ 6 kg·cm stall** to cross the speed breakers (5 fails, 6 passes) — buy one, do the bottle test in ASSEMBLY.md §0, then buy the rest. | P-01 |
| D2 | **Front wheel, one piece** Ø140 | 2 | Print **PETG** (RR-07): hub + hard tread together (a rigid PETG tread can't be stretched over the bead lips). The hard front lets the skid steer turn. | RR-07 |
| D3 | **Rear wheel** = hub + tyre | 2 + 2 | Hub RR-05 in PETG; tyre RR-06 in **TPU 95A**, stretched over the hub between the bead lips (grip for the ramp and speed breakers). | RR-05 / RR-06 |
| D4 | M3 × 5 cup-point grub screw | 4 | Hub → shaft flat. Hex-key access through the hole in the tyre and rim | — |
| D5 | M3 × 6 socket cap screw | 8 | Motor gearbox face → tub side wall (2 per motor) | — |
| D6 | **Cytron MDD10A Rev2.0** dual motor driver (already bought) | 1 | 5–30 V, 10 A continuous / 30 A peak per channel, 3.3 V logic, PWM + DIR inputs, 84.5 × 62 mm. Channel 1 = both left motors in parallel, channel 2 = both right. On the deck top, 4 × M3 × 10 self-tapping screws into printed bosses | P-05 |
| D6b | 10 kΩ resistor | 2 | PWM1 / PWM2 pull-downs (no twitch while the ESP32 boots) | — |
| D7 | 22 AWG silicone wire, red/black | 2 m | Motor leads | — |

Result: Ø140 wheels, wheelbase 152 mm, track 168 mm, overall 293.7 × 196 mm.
~0.34 m/s loaded, 0.44 m/s free.

### 1b. Robot arm — the thenar-arms MG996R follower R3 (unchanged)

Full part list and print notes: thenar-arms `so101-mg996r/R3-PRINT.md`.

| # | Part | Qty | Spec | CAD |
|---|---|---:|---|---|
| A1 | MG996R positional servo (180°) | 6 | J1 pan, J2 lift, J3 elbow, J4 wrist flex, J5 wrist roll, J6 gripper | MG996R_Nominal_R3 |
| A2 | 25T metal disc horn Ø20, 4 × M3 on 14 mm PCD | 6 | Must match your servo spline | Metal_Horn_D20_PCD14_R3 |
| A3 | Horn-to-link screws M3 × 8 | 24 | | — |
| A4 | Servo tab screws M3 × 12 + nut + 2 washers | 24 / 24 / 48 | | — |
| A5 | Arm prints (R3): Base, Shoulder, Upper arm, Forearm, Wrist pitch/roll, Gripper body, Moving jaw | 7 | PETG. CAD mass 368 g | thenar-arms STLs |
| A6 | PCA9685 16-channel PWM driver | 1 | Servo PWM, I²C 0x40 | P-04 |
| A7 | 6 V DC-DC buck, ≥ 10 A (XL4016 / "300 W 20 A" class), adjustable | 1 | 6 × MG996R; TowerPro stall 1.4 A each → 8.4 A worst case | P-06 |
| A8 | Servo extension leads 15–30 cm | 6 | Through the deck slot to the PCA9685 | — |
| A9 | **TPU finger pads**, 4 mm (recommended) | 2 | The jaws stop 19.7 mm apart at the 0° gripper limit: pads let it hold a thin marker (Robonardo, 130 pts) and grip thermocol better | — |
| A10 | Arm base → deck: M3 × 20 SHCS + washer + nyloc nut | 4 | Through four of the base's vent slots, nut under the deck | — |

Gripper opening (from the CAD): 50 mm cube at ~28°, 60 mm cube / Ø60 cylinder at ~38°,
79 mm maximum inner gap at 60°.

---

## 2. Electronics and power

| # | Part | Qty | Spec |
|---|---|---:|---|
| E1 | ESP32-DevKitC (ESP32-WROOM-32E, 38-pin) | 1 robot + 1 controller | Robot: Wi-Fi AP + control. Controller: the leader's existing ESP32 |
| E2 | 3S LiPo 2200 mAh 30C, XT60 | 1 (+1 spare) | 106 × 34 × 26 mm max. Peak 10.6 A, ~28 min per pack at average load |
| E3 | KCD4 DPST rocker 30 A, red (kill switch) | 1 | Panel cut-out 22.2 × 30.2 mm; in series with battery + |
| E4 | Fuse holder + fuse, 10–15 A | 1 | Blade or 5 × 20 mm glass (the glass panel-mount holder you bought is fine — use a 10 A fuse) |
| E5 | XT60 male/female pair | 1 | |
| E6 | MP1584 mini buck, set to 5.0 V | 1 | ESP32 supply |
| E7 | Resistors 100 kΩ + 27 kΩ | 1 each | Battery voltage sense on GPIO34 |
| E8 | 16 AWG silicone wire | 1 m | Battery → fuse → switch → drivers/bucks |
| E9 | Dupont / JST-XH leads, heat-shrink, zip ties | 1 lot | |
| E10 | M2.5 × 6 self-tapping screws | 20 | Boards to the floor standoffs |
| E11 | LiPo balance charger + LiPo safe bag | 1 | |

### Controller additions (on the thenar-arms L1 leader)

| # | Part | Qty | Spec |
|---|---|---:|---|
| C1 | 2-axis analog thumb joystick module | 1 | 3.3 V supply; VRx → GPIO34, VRy → GPIO35 |
| C2 | SPST toggle switch (ENABLE) | 1 | GPIO32 to GND |
| C3 | Momentary push button (SPEED) | 1 | GPIO33 to GND |
| C4 | USB power bank + cable | 1 | Powers the leader ESP32 |

The leader itself (6 × AS5600, TCA9548A, 12 × 688ZZ bearings, magnets, prints) is the
thenar-arms L1 BOM — no changes.

---

## 3. Chassis prints (PETG unless noted)

| # | Part | Qty | Bed size | Mass | Notes |
|---|---|---:|---|---:|---|
| RR-01 | Chassis tub | 1 | 240 × 138 × 41 mm | 144 g | Print floor-down, 4 walls; the motor U-slots' round tops print as short arches (no support needed below 26 mm) |
| RR-02 | Deck plate | 1 | 250 × 138 × 11 mm | 119 g | Arm fence, MDD10A bosses + wire slot, ESP32 standoff holes; fits the P1S 256 mm bed |
| RR-03 | Battery cage | 1 | 128 × 44 × 27 mm | 22 g | |
| RR-04 | Battery retaining bar | 2 | 10 × 44 × 3 mm | 1 g | |
| RR-05 | Rear wheel hub | 2 | Ø131 × 28 mm | 68 g | PETG, spoke disc down |
| RR-06 | Rear tyre | 2 | Ø140 × 25 mm | 44 g | TPU 95A |
| RR-07 | Front wheel (one piece) | 2 | Ø140 × 28 mm | ~115 g | PETG, inner face down |

**Ready-to-print P1S plates: `cad/print/` (5 plates, see cad/print/PRINT.md).** Single STLs: `cad/stl/`. Filament for the rover plates: ≈ 0.81 kg PETG + ≈ 87 g TPU, ≈ 28.6 h on a P1S (estimate ±25 %).

### Chassis fasteners

| Item | Qty | Use |
|---|---:|---|
| M3 heat-set insert (Ø4.0 bore, ~5.7 mm long) | 4 | Tub corner columns |
| M3 × 10 SHCS | 4 | Deck → tub (counterbored) |
| M3 × 8 SHCS + nyloc | 2 | Battery cage → floor |
| M3 × 8 self-tapping (or M3 into 2.6 mm pilot) | 4 | Battery bars → cage bosses |
| M2.5 × 10 brass standoff (F-F) + 2 × M2.5 × 6 screws | 2 | ESP32 under the deck (zip-tie the board to them) |
| M3 × 10 self-tapping screw (or M3 × 10 machine screw into the 2.6 mm pilot) | 4 | Cytron MDD10A → deck-top bosses |

---

## 4. Not in the BOM on purpose

* No adhesives, magnets, hooks or suction on the gripper (rule) — the jaws are purely mechanical.
* No ready-made Lego. The JGA25 gearboxes are ready-made gear assemblies, which the rules allow.
* No camera — not needed for manual control and saves weight/power.

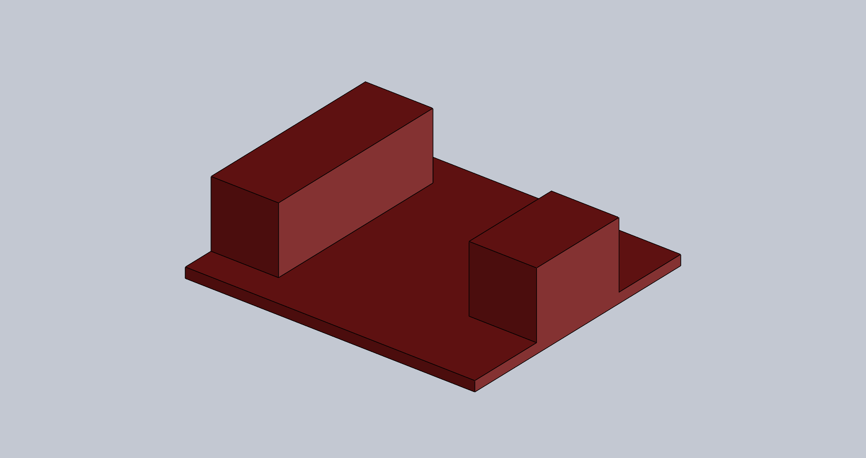
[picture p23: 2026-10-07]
cad/renders/parts/P-05_Cytron_MDD3A.png

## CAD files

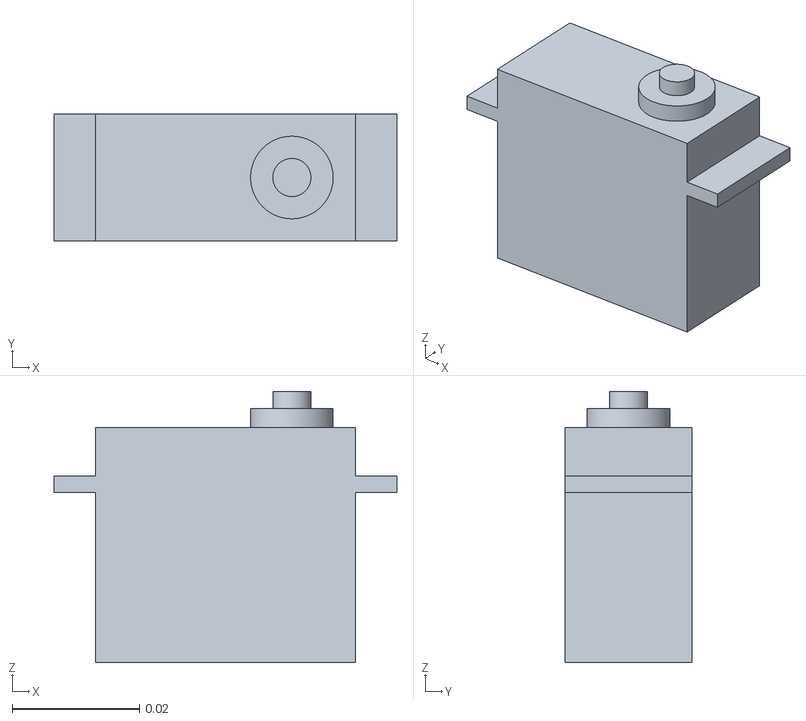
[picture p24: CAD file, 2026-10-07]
analysis/so101_description/meshes/collision/MG996R_Nominal_R3_body0.stl
0.054 x 0.02 x 0.0427

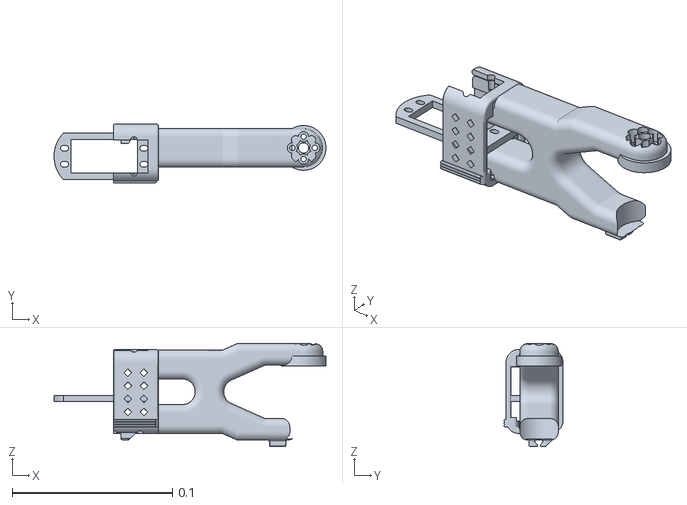
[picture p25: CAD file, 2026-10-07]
analysis/so101_description/meshes/visual/Forearm_MG996R_R3.STL
0.17 x 0.0369 x 0.0644

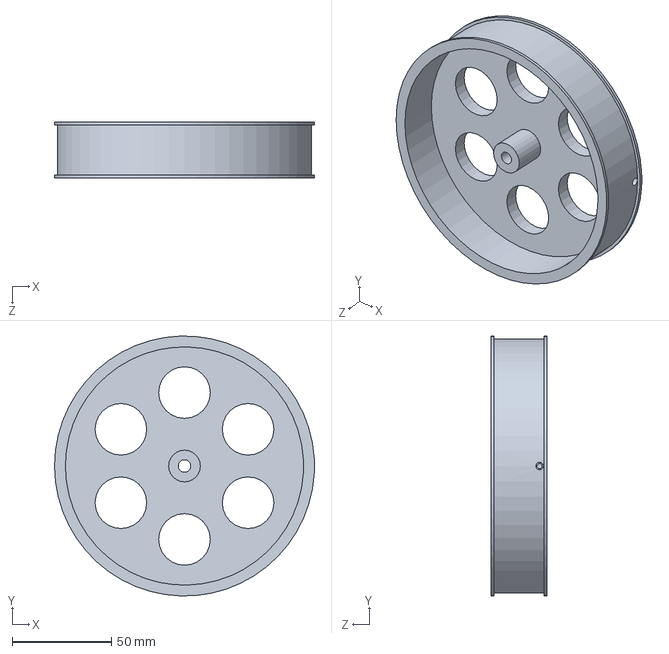
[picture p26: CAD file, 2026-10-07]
cad/parts/RR-05_Wheel_Hub_6mm.SLDPRT
131.0 x 130.9 x 28.0 mm

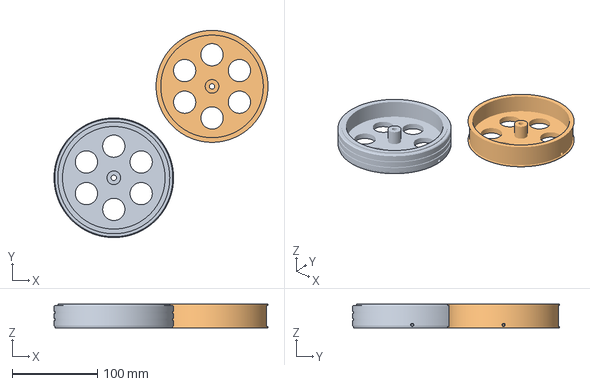
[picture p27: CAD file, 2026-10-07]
cad/print/creality/SparkX_i7_Wheels_6mm_FrontWheel_RearHub.3mf
250.5 x 242.5 x 28.0 mm
RR-07_Front_Wheel_PETG_6mm_1
RR-05_Wheel_Hub_6mm_2

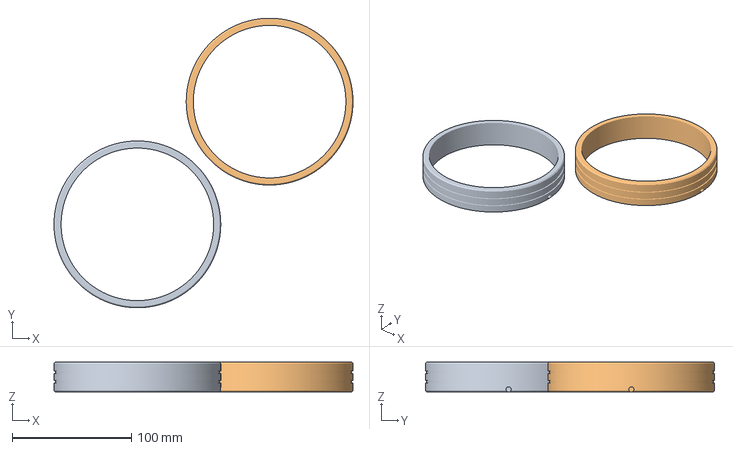
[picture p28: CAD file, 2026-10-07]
cad/print/P1S_Rover_5_RearTyres_TPU.3mf
251.0 x 243.0 x 25.0 mm
RR-06_Wheel_Tyre_1
RR-06_Wheel_Tyre_2

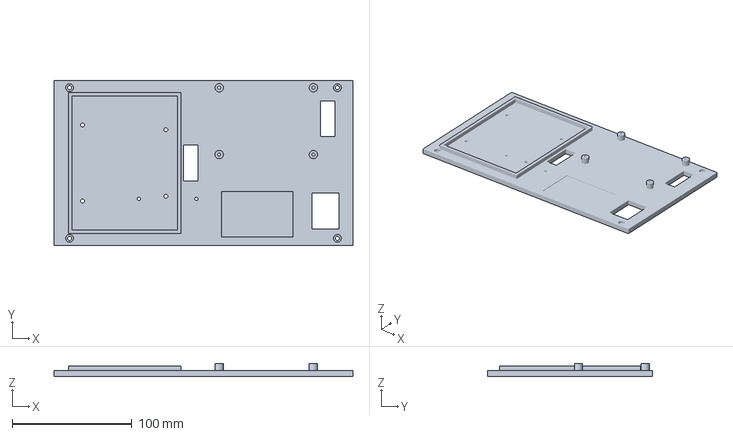
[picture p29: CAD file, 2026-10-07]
cad/print/sliced/P1S_Rover_2_Deck_sliced.3mf
250.0 x 138.0 x 11.0 mm

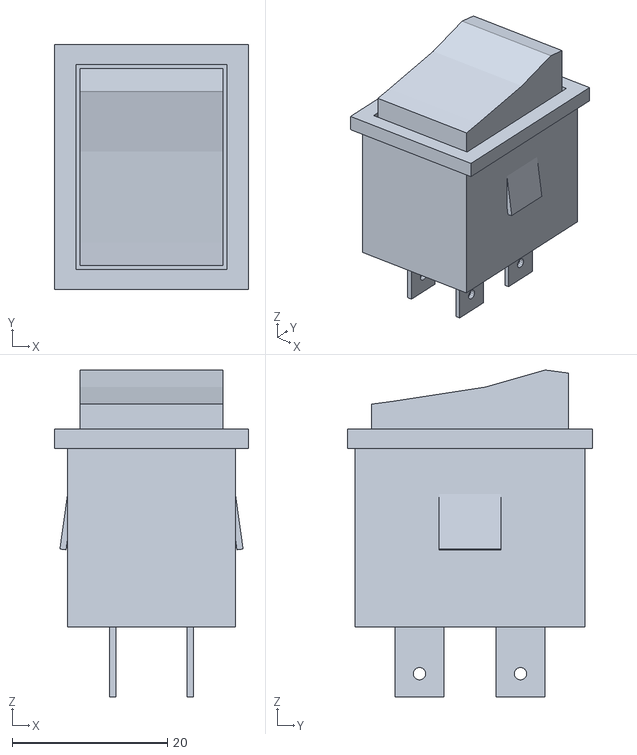
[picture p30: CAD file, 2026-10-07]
cad/stl/P-08_Kill_Switch_KCD4.STL
25.0 x 31.5 x 42.1

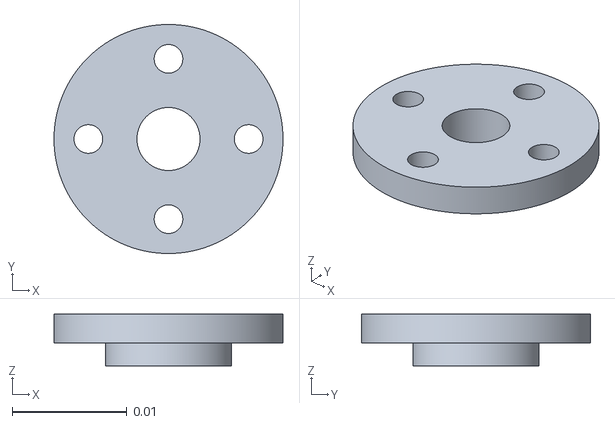
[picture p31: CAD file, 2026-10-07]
sim/arm_src/meshes/Metal_Horn_D20_PCD14_R3_body0.stl
0.02 x 0.02 x 0.0045

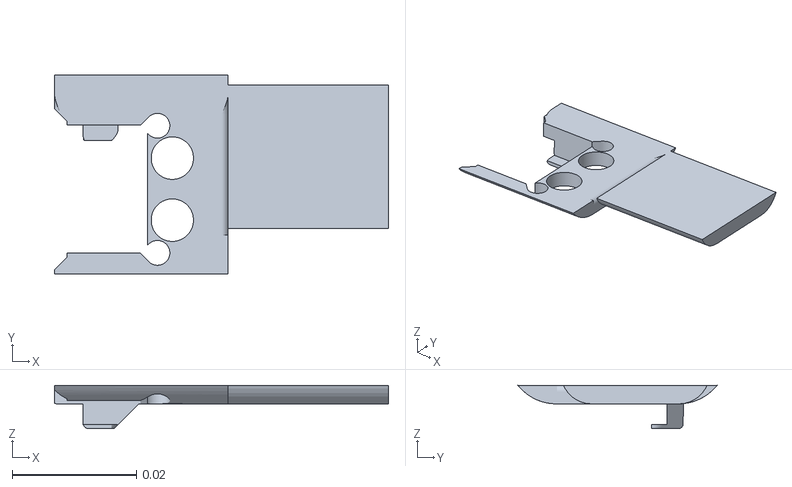
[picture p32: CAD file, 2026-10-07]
analysis/so101_description/meshes/collision/Forearm_MG996R_R3_body2.stl
0.0538 x 0.0321 x 0.00699

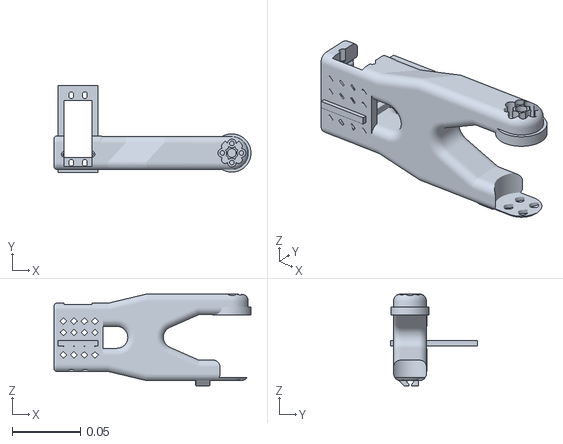
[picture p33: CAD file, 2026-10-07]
analysis/so101_description/meshes/visual/Upper_arm_MG996R_R3.STL
0.144 x 0.064 x 0.0673

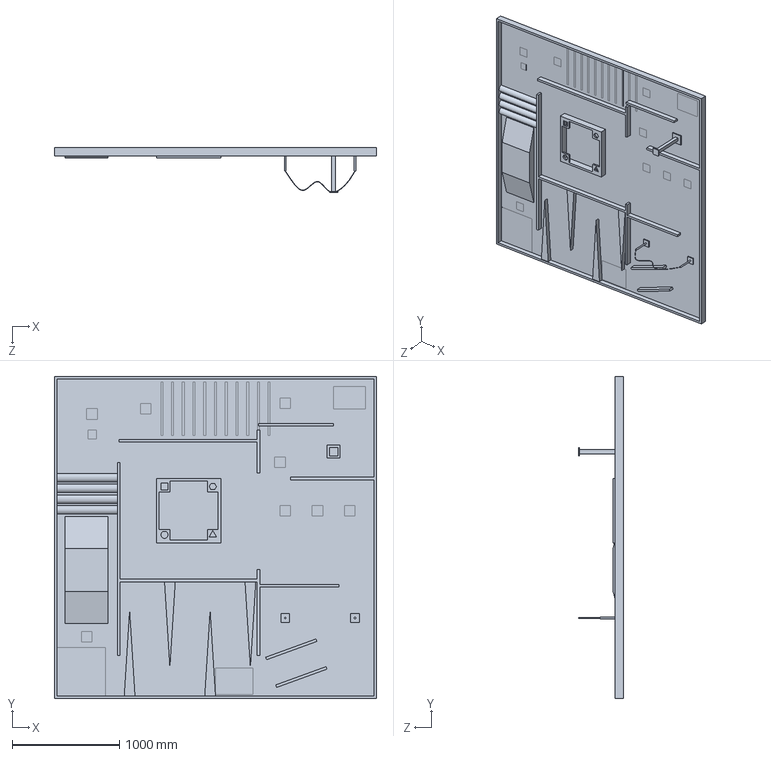
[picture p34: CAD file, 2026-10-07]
cad/arena/RA-01_Arena_Board.SLDPRT
3000.0 x 3000.0 x 419.1 mm

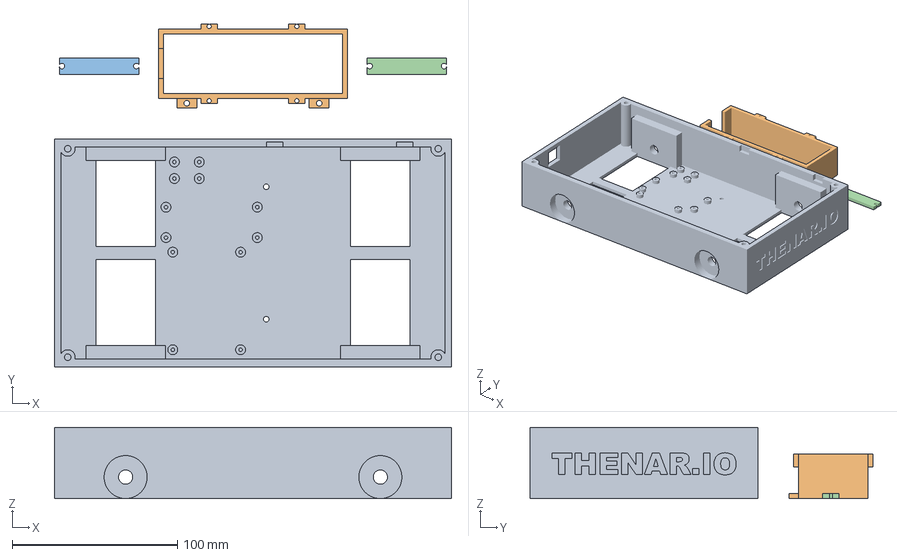
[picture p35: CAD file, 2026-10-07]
cad/print/creality/SparkX_i7_Plate1_Tub_Cage_Bars_FIXED.3mf
240.0 x 207.5 x 43.0 mm
RR-01_Chassis_Tub_1
RR-03_Battery_Cradle_2
RR-04_Battery_Bar_3
RR-04_Battery_Bar_4

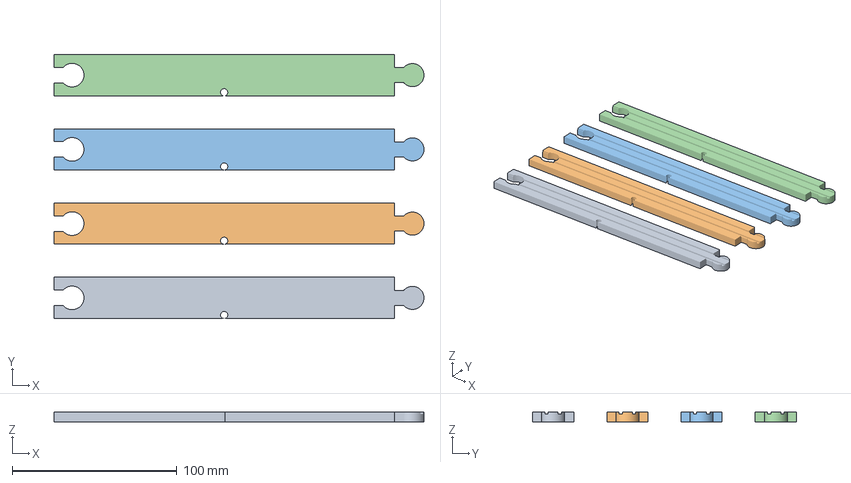
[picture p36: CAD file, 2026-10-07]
cad/print/P1S_Rover_5F_FlatTyreStrips_2tyres_TPU.3mf
224.3 x 160.0 x 6.00 mm
RR-06F_Tyre_Strip_Half_1
RR-06F_Tyre_Strip_Half_2
RR-06F_Tyre_Strip_Half_3
RR-06F_Tyre_Strip_Half_4

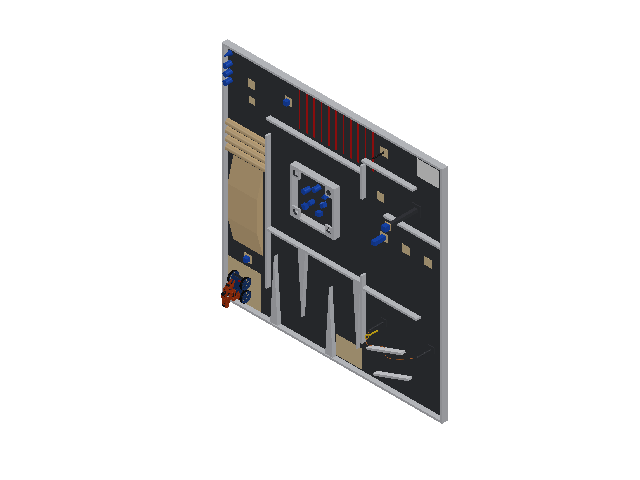
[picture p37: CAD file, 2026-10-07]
cad/arena/RoboReach_Arena.SLDASM
RA-01_Arena_Board
RA-10_Cube_50 x 8
RA-14_Marker
RA-11_Cube_60
RA-12_Cylinder_60x80 x 5
RA-13_Cone_R30x100
RA-16_Escape_Triangle
RA-17_Escape_Hexagon
RA-15_Buzz_Loop
RR-01_Chassis_Tub
RR-02_Deck_Plate
RR-03_Battery_Cradle
P-02_LiPo_3S_2200mAh
P-08_Kill_Switch_KCD4_30A
RR-04_Battery_Bar x 2
P-01_Motor_JGA25-370_12V x 4
RR-05_Wheel_Hub x 4
RR-06_Wheel_Tyre x 4
P-06_Buck_6V_10A
P-05_Cytron_MDD3A x 2
P-04_PCA9685_16ch
P-07_Buck_5V_MP1584
P-03_ESP32_DevKitC
Base_MG996R_R3
MG996R_Nominal_R3 x 6
Shoulder_MG996R_R3
Upper_arm_MG996R_R3
Forearm_MG996R_R3
Wrist_pitch_roll_MG996R_R3
Gripper_body_MG996R_R3
Moving_jaw_MG996R_R3
Metal_Horn_D20_PCD14_R3 x 6

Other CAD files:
cad/assemblies/Thenar_Walker.SLDASM
cad/arena/Terrain_Check.SLDASM
cad/parts/RR-05_Wheel_Hub.SLDPRT
cad/print/sliced/P1S_Rover_4b_FrontWheel_RearHub_6mm_shaft_sliced.3mf
analysis/so101_description/meshes/collision/Base_MG996R_R3_body0.stl
analysis/so101_description/meshes/collision/Forearm_MG996R_R3_body0.stl
analysis/so101_description/meshes/collision/Forearm_MG996R_R3_body1.stl
analysis/so101_description/meshes/collision/Gripper_body_MG996R_R3_body0.stl
analysis/so101_description/meshes/collision/Moving_jaw_MG996R_R3_body0.stl
analysis/so101_description/meshes/collision/Shoulder_MG996R_R3_body0.stl
analysis/so101_description/meshes/collision/Upper_arm_MG996R_R3_body0.stl
analysis/so101_description/meshes/collision/Wrist_pitch_roll_MG996R_R3_body0.stl
analysis/so101_description/meshes/visual/Base_MG996R_R3.STL
analysis/so101_description/meshes/visual/Gripper_body_MG996R_R3.STL
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

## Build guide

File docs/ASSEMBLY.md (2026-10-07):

# Build guide — Thenar Walker

Open `cad/assemblies/Thenar_Walker.SLDASM` (configuration **STOW**) beside this guide.
Part numbers (RR-xx printed, P-xx purchased) match the CAD and `docs/BOM.md`.

## 0. Before printing
1. Measure your JGA25 motor: gearbox Ø25, shaft 4 mm D, shaft length from the face ≥ 9 mm,
   face holes 2 × M3 at 17 mm. If different, change `cad/tools/design.py` and rebuild
   (`python cad/tools/build_parts.py`).
2. Lay your boards on the CAD footprints (`design.BOARDS`) — move any that differ.
3. **Motor torque test (before buying all four).** Sellers' torque figures for the "25GA-370 12 V 60 RPM"
   disagree, and the robot needs ≥ 6 kg·cm stall. Print one wheel, put it on the motor, tie a string to
   the tyre (7 cm radius) and hang a filled 1 L water bottle (~1 kg = 7 kg·cm). At 12 V the motor must
   lift it. If it stalls with a 500 ml bottle, it's the weak version — return it.
   **100 RPM version** (simulated 2026-10-05, `sim/out/run_100rpm_*.txt`): it passes the whole course only if it is
   at least ~4.9 kg·cm at stall (4.5 gets stuck on the speed breakers). Test: it must lift a **750 ml** bottle on the
   7 cm string at 12 V. Drive the speed breakers in normal/fast mode (momentum helps) and turn near the poles in
   precision mode (in normal mode it is fast enough to brush the corridor wall).
   Easiest with the MDD10A: battery → B+/B−, motor → M1A/M1B, press the **M1A** test button (no ESP32 needed).

## 1. Print
Print the 5 ready plates in `cad/print/` (see `cad/print/PRINT.md`): tub + cage + bars, deck, 2 × (front wheel + rear hub),
and the 2 TPU rear tyres. Plus the seven thenar-arms R3 arm parts.

## 2. Tub
1. Melt 4 × M3 heat-set inserts into the corner columns.
2. Screw the battery cage (RR-03) to the floor: 2 × M3 × 8 + nyloc from below.
3. Drop each motor into its U-slot from above, gearbox face against the wall, terminals inward.
   2 × M3 × 6 through the wall into the gearbox face. Solder leads first.
4. Screw the 6 V buck, PCA9685 and the 5 V buck to their floor standoffs (M2.5 self-tap).
   The two empty standoff pads in front of the buck (where the old MDD3A boards were) are spare:
   use them for the fuse holder or a wire tie-down.
5. **Set the 6 V buck to 6.0 V and the 5 V buck to 5.0 V on the bench before connecting anything.**
6. Wire per `docs/WIRING.md`: XT60 → fuse → kill switch → VBAT bus. Leave the kill switch OFF.

## 3. Wheels
1. Rear: stretch a TPU tyre over each RR-05 hub between the bead lips. Front: the RR-07 wheels are one piece.
2. Push each wheel on the D-shaft until it is ~1 mm off the wall; tighten the M3 grub screw onto the
   flat through the hole in the tread.

## 4. Deck and arm
1. Screw two M2.5 × 10 brass standoffs under the deck and zip-tie the robot ESP32 to them (USB towards the rear).
2. Snap the kill switch into the deck cut-out, wire it, route the six servo leads up through the
   slot in front of the fence.
3. **Motor driver (Cytron MDD10A)** on the deck top, front-left: blue terminals facing forward, 4 × M3 × 10
   self-tapping screws into the printed bosses. Feed B+/B− and the 4 motor-pair wires up through the slot
   in front of the terminals; the 5 signal wires (GND, PWM2, DIR2, PWM1, DIR1) come up through the servo slot
   to the white plug at the back of the board. Details: WIRING.md → "Motor driver".
4. Put the battery in its cage, lead out of the +X window, screw on the two bars.
5. Deck onto the tub: 4 × M3 × 10 into the inserts.
6. Assemble the thenar-arms R3 follower (its own guide). Sit the arm base inside the deck fence
   and bolt it with 4 × M3 × 20 + washers through the base vent slots at (−14.2, ±31.7) and
   (55.5, ±27.8) mm (arm frame) — nyloc nuts under the deck. Plug servos J1..J6 into PCA9685 ch 0..5.

## 5. Firmware
1. `python firmware/tools/new_key.py "Your Team Name"` — creates the secret `team_config.h`.
2. Compile: `powershell -File firmware/tools/compile_firmware.ps1` (or Arduino IDE, board
   "ESP32 Dev Module", add `firmware/libraries` as a sketchbook library folder).
3. Flash `thenar_walker_bot` to the robot ESP32 and `thenar_walker_controller` to the leader ESP32.
4. Leader calibration (once): hold the leader at the thenar-arms HOME pose, send `ZERO` on the
   serial monitor; fix any reversed axis with `SIGN <axis> -1`; centre the joystick with `JOYZERO`.
5. Servo calibration (once, arm unloaded, horns off): measure each MG996R's zero and direction,
   put them in `firmware/thenar_walker_bot/calibration.h`, set `FOLLOWER_CALIBRATED = true`,
   reflash. Until then the robot drives but the arm stays limp (by design).

## 6. First power-up (wheels off the ground)
1. Robot in STOW, leader folded to STOW, controller ENABLE **off**. Kill switch ON.
2. Controller LED stops fast-blinking when it joins `<Team>_TF`; robot LED blinks (DISARMED/HOLD).
3. ENABLE on → robot LED solid = ACTIVE (arm engages only if the leader matches STOW within 6°).
4. Check each wheel direction with the joystick; swap a motor's two leads if one is backwards.
5. **Failsafe test:** while driving and holding a cube, switch the controller off → wheels stop
   at once, arm freezes, gripper keeps the cube, and nothing moves until the controller is back
   and sends new commands. Repeat at inspection.

## 7. Before every run
Battery ≥ 11.4 V (controller prints `batt` mV), kill switch reachable, team_config not the example,
robot folded to STOW and inside the 300 × 200 × 300 box.

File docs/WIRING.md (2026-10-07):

# Wiring — Thenar Walker

Pin numbers here are the ones in `firmware/thenar_walker_bot/thenar_walker_bot.ino` and
`firmware/thenar_walker_controller/thenar_walker_controller.ino`. If you change one, change both.

## Power tree (robot)

```
3S LiPo 2200 mAh (11.1 V nom, 12.6 V full)  ── XT60 ──┐
                                                      │
                            fuse 10–15 A (blade or 5×20 glass, inline, close to the XT60)
                                                      │
                          KCD4 30 A rocker = KILL SWITCH (both poles in parallel on +)
                                                      │  battery +  ("VBAT bus", 16 AWG)
        ┌─────────────────────────────────────┬───────┴─────────┬────────────────────┐
   MDD10A  B+  (B− to battery −)          6 V buck IN+        5 V buck IN+      100k ─┬─ 27k ─ GND
   M1A/M1B: FL + RL motors in parallel     (>= 10 A)           (MP1584)               │
   M2A/M2B: FR + RR motors in parallel      │ 6.0 V              │ 5.0 V            GPIO34 (battery sense)
                                     PCA9685 V+ terminal    ESP32 5V pin
                                     (servo rail, 6 x MG996R)   ESP32 3V3 -> PCA9685 VCC (logic)
All grounds common: battery −, MDD10A B− and input-header GND, both buck GND, PCA9685 GND, ESP32 GND.
```

* Every voltage on the robot is <= 12.6 V (rule: <= 24 V DC between any two points).
* The kill switch is in series with the battery positive *before* everything, so it shuts the
  whole robot down (motors, servos, ESP32). It is on the deck, front right, reachable from above.
* Set the 6 V buck to **6.0 V with no load before** connecting the PCA9685 V+ (MG996R: 4.8–6.6 V).
* Never power servos from the ESP32 or USB.
* Battery: inside the printed cage (RR-03) with two screwed bars (RR-04) — it cannot fall out if
  the robot rolls over (rule). Leads leave through the cage's +X end window.

## Robot ESP32 (ESP32-DevKitC, hung under the deck)

| ESP32 pin | Goes to | Notes |
|---|---|---|
| GPIO21 | PCA9685 SDA | I²C 400 kHz |
| GPIO22 | PCA9685 SCL | |
| GPIO13 | PCA9685 OE | HIGH = servo outputs off (boot state); firmware drives LOW once engaged |
| GPIO25 | MDD10A **PWM1** (header pin 4) | Left motors speed |
| GPIO26 | MDD10A **DIR1** (header pin 5) | Left motors direction |
| GPIO16 | MDD10A **PWM2** (header pin 2) | Right motors speed |
| GPIO17 | MDD10A **DIR2** (header pin 3) | Right motors direction |
| GND | MDD10A **GND** (header pin 1) | must be connected, or the inputs float |
| GPIO34 | battery divider mid-point | 100 kΩ (to VBAT) / 27 kΩ (to GND) |
| GPIO2 | on-board LED | solid = ACTIVE, blinking = HOLD / waiting |
| 5V / GND | 5 V buck out | |
| 3V3 | PCA9685 VCC | logic only |

### Motor driver: Cytron MDD10A Rev2.0 (one board, both sides)

* Mounted on top of the deck, front-left, on 4 printed bosses (4 × M3 × 10 self-tapping screws).
  The blue screw terminals face forward; all power and motor wires go down through the slot in front of them.
* Terminal block (left to right in the manual): **M1B, M1A, B+, B−, M2A, M2B**.
  * M1A / M1B: **both left motors in parallel** (front-left and rear-left: both red wires in M1A,
    both black wires in M1B).
  * M2A / M2B: **both right motors in parallel**, same way (red → M2A, black → M2B).
  * B+ from the kill switch output, B− to battery −.
* The 5-pin input header uses the supplied white 2510 plug: **1 GND, 2 PWM2, 3 DIR2, 4 PWM1, 5 DIR1**.
  Run the 5 jumper wires up through the arm's servo-cable slot to the header.
* Logic: 3.3 V is fine (high ≥ 3 V). PWM 20 kHz (the board's maximum). PWM low → both outputs low (brake);
  DIR low → current A→B, DIR high → B→A.
* Recommended: a **10 kΩ resistor from PWM1 to GND and from PWM2 to GND** (at the plug), so the
  wheels cannot twitch while the ESP32 is booting and its pins are still floating.
* Current: each 25GA-370 stalls at about 1.3 A, so 2 motors on one channel draw 2.6 A worst case
  (MDD10A: 10 A continuous per channel). No heat sink needed.
* **Test buttons**: M1A / M1B / M2A / M2B on the board spin the motors with no ESP32 connected. Use
  them for the first power-up and the bottle test (ASSEMBLY.md §0).
* The right-side motors face the other way, so the firmware inverts the right channel (`SIDE_SIGN`).
  If **both** wheels on one side spin backwards, swap that side's M_A / M_B wires. If only **one** wheel
  of a side spins backwards, that motor's two wires are swapped relative to its partner: fix them so
  both motors on that channel match.

### PCA9685 servo channels (same order as the thenar-arms follower)

| Channel | Joint | MG996R location |
|---|---|---|
| 0 | J1 shoulder pan | in the base |
| 1 | J2 shoulder lift | shoulder |
| 2 | J3 elbow flex | upper arm |
| 3 | J4 wrist flex | forearm |
| 4 | J5 wrist roll | wrist |
| 5 | J6 gripper | gripper body |

Servo leads run down through the deck slot in front of the arm fence.
`calibration.h` ships with `FOLLOWER_CALIBRATED = false`: the robot drives, but the arm PWM stays
off until you measure each servo's zero/direction unloaded and set it to `true`.

## Controller (the thenar-arms L1 encoder leader)

Keep the leader's existing ESP32 + TCA9548A (0x70) + 6 × AS5600 wiring from thenar-arms
(`so101-mg996r/ENCODER-LEADER.md`, SDA 21 / SCL 22). Add:

| ESP32 pin | Goes to |
|---|---|
| GPIO34 | joystick VRx (turn) |
| GPIO35 | joystick VRy (throttle) |
| 3V3 / GND | joystick VCC / GND (3.3 V, not 5 V — the ADC tops out at ~3.1 V) |
| GPIO32 | ENABLE toggle switch to GND (on = robot may move) |
| GPIO33 | SPEED push button to GND (cycles precision 35 % / normal 65 % / fast 100 % drive; turning 50 / 75 / 100 %) |

Power the controller from a USB power bank. Only one person operates: right hand on the leader
arm handle, left hand on the joystick (rule: one operator).

## Link and failsafe behaviour (what the judges will ask)

* Robot runs a WPA2 access point named **`<TeamName>_TF`** (spaces removed, first 20 characters),
  max 1 connected station.
* Every packet is HMAC-SHA256 signed with a 32-byte key only your two ESP32s know
  (`firmware/tools/new_key.py`); a random per-pairing session id and increasing sequence
  numbers reject replays. Packets from any other IP/port are ignored.
* No valid command for 250 ms, or ENABLE switched off, or a leader encoder fault → **HOLD**:
  wheels stop immediately, the arm stops where it is, the gripper keeps its PWM (keeps holding),
  and nothing moves again until a *new* valid command arrives.
* Power-up: the robot stays DISARMED (servo PWM off) until the leader arm is within 6° of the
  robot's STOW pose, so the arm cannot jump when it engages.
* Demonstrate at inspection: switch the controller off → wheels stop, arm freezes, gripper holds.

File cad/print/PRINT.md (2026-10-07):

# Rover print plates — Bambu Lab P1S

Five plates, everything for the driving base. (The arm plates are in thenar-arms.)
Open a `.3mf` in Bambu Studio → it loads already placed on the 256 × 256 bed → pick the filament → slice → print.
If Bambu Studio asks "load as a single object with multiple parts?", answer **No**.

| # | File | Material | Parts | Height | Time* | Filament* |
|---|---|---|---|---|---|---|
| 1 | `P1S_Rover_1_Tub_Cage_Bars.3mf` — **tub v2**: mounts for the 370 plastic-gearbox motors (M8 collar + nut pocket), walls 100 high for the 3 mm wooden deck, THENAR.IO / THENARLABS engraved; cage along Y | PETG | chassis tub, battery cage, 2 battery bars | 43 mm | 6 h 51 min (sliced) | 252 g (sliced) |
| 2 | `P1S_Rover_2_Deck.3mf` | PETG | deck plate (250 mm long) + 4 bosses for the Cytron MDD10A | 11 mm | ~3.0 h (Bambu Studio: 3 h 27 min) | ~127 g (sliced: 117 g) |
| 3 | `P1S_Rover_3_FrontWheel_RearHub_A_PRINT_FIRST.3mf` | PETG | 1 front wheel (one piece) + 1 rear hub | 28 mm | ~5.4 h | ~211 g |
| 4 | `P1S_Rover_4_FrontWheel_RearHub_B.3mf` | PETG | 1 front wheel + 1 rear hub | 28 mm | ~5.4 h | ~211 g |
| 4b | `P1S_Rover_4b_FrontWheel_RearHub_6mm_shaft.3mf` — **use instead of plate 4 for the local 370 plastic-gearbox motor** (6 mm round shaft): 6.3 mm round hole + M3 grub | PETG | 1 front wheel + 1 rear hub | 28 mm | 6 h 7 min (sliced) | 202 g (sliced) |
| 5F | `P1S_Rover_5F_FlatTyreStrips_2tyres_TPU.3mf` — **flat alternative to plate 5: 2 tyres** as 4 straight half-strips with a click (puzzle) joint, 2 % short so they sit stretched on the hub; superglue the joints | **TPU 95A** | 4 half-strips = 2 tyres | 6 mm | 5 h 40 min (sliced) | 84 g (sliced) |
| 5G | `P1S_Rover_5G_FlatTyreStrips_4tyres_TPU.3mf` — same strips, **8 half-strips = 4 tyres (2 + 2 spare)** | **TPU 95A** | 8 half-strips | 6 mm | 11 h 13 min (sliced) | 168 g (sliced) |
| 5 | `P1S_Rover_5_RearTyres_TPU.3mf` | **TPU 95A** | 2 rear tyres | 25 mm | ~7.7 h | ~87 g |

\* estimated from the real geometry (`cad/tools/estimate_print_time.py`, ±25 %); Bambu Studio shows the exact numbers after slicing.
**Total ≈ 28.6 h of printing, ≈ 0.81 kg PETG + ≈ 87 g TPU** (rover only — buy a 1 kg PETG spool and a small TPU spool).

## Who prints what

| Printer | Plates | Time | Filament |
|---|---|---|---|
| **Friend** — `Friend_Print_Package_Plates_1_and_5.zip` | 1 (tub + cage + bars), 5 (TPU rear tyres) | ~15 h | ~260 g PETG + ~90 g TPU |
| **Us** | 3 (first!), 4, 2 | ~14 h | ~550 g PETG |

The friend's printer needs a ≥ 256 × 256 mm bed and a direct-drive extruder for TPU.

**Print plate 3 first:** its front wheel is the one you put on the first motor for the 1 L water-bottle test.

## Settings

| | PETG plates (1–4) | TPU plate (5) |
|---|---|---|
| Profile | Bambu PETG Basic / generic PETG, 0.20 mm Standard | Bambu TPU 95A / generic TPU, 0.20 mm |
| Walls | 4 | 3 |
| Infill | 30 % gyroid | 20 % gyroid |
| Supports | **none** (checked: only short bridges and ≤ 1.5 mm ledges) | none |
| Plate | textured PEI (glue stick on smooth PEI) | textured PEI |
| Notes | tub: add a 5 mm brim if corners lift | dry the TPU first; slow (max volumetric ~3.6 mm³/s) |

## Which way up (already set in the files)

| Part | On the bed |
|---|---|
| RR-01 tub | floor down, walls up — motor U-slots, vent slots and USB hole print as short bridges |
| RR-02 deck | flat underside down, arm fence and the 4 MDD10A bosses up (the ESP32 now hangs on 2 brass M2.5 × 10 standoffs, so nothing sticks out below) |
| RR-03 cage / RR-04 bars | open box up / flat |
| RR-05 rear hub | spoke disc (inner face) down |
| RR-07 front wheel | inner face down (one piece: hub + hard tread) |
| RR-06 rear tyre | ring standing on its edge |

## After printing

1. Heat-set 4 × M3 inserts into the tub's corner columns.
2. Clean the 4 mm D-bore of every wheel with a 4 mm drill by hand if the shaft is tight.
3. Tap the grub-screw holes (Ø2.6) with an M3 tap, or let the M3 grub screw cut its own thread.
4. Stretch the TPU tyres onto the two rear hubs (TPU = rear, hard one-piece wheels = front).

Single-part STLs for re-arranging are in `cad/stl/`. Rebuild the plates after any CAD change:
`python cad/tools/build_parts.py` then `python cad/tools/make_plates.py`.

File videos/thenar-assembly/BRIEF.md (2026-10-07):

---
workflow: general-video
flow: automation
storyboard: no
message: "Build the Thenar Walker rover step by step, and wire every connection correctly"
destination: team-laptop
aspect: 1920x1080
language: en
audience: the Thenar Walker build team (RoboReach 2026-27)
length: 240s
angle: assembly-manual
---

## Intent

A full 3D assembly film of the Thenar Walker rover built from the project's real CAD parts (tub v2,
370 gear motors with M8 collar + nut, wheels + TPU tyres, battery cage, boards, 3 mm wooden deck,
Cytron MDD10A, kill switch, thenar-arms follower arm). Each part animates into place, then every
electrical connection draws itself: power path, motors to the driver channels, ESP32 signal pins,
servo leads. User's words: "full assembly video with 3d animations ... and connections to each part
of it, each connections please".

## Customizations

- On-screen labels only (step titles, part names, screw sizes, pin names). No voiceover.
- About 4 minutes, slower pace, close-ups on screws, nuts and pins.

## Notes

- Geometry truth: cad/tools/tub_v2.py (tub v2 layout), cad/tools/design.py, docs/WIRING.md.
- Motor can/cap are estimated (total length 50 mm from the gearbox face).
- No music was requested; the film is silent.

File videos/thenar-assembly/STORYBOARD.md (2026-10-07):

---
message: "Build the Thenar Walker rover step by step, and wire every connection correctly"
mode: autonomous
storyboard: no
---

One continuous Three.js scene (index.html) — no hard cuts, so the steps are frames of a single composition.
Motion: rules `3d-camera-flight` (camera path per step) + assemble-into-place part events; HUD cards with staggered entrances.

## Frame 1 — Title (0–10 s)
status: built · src: index.html · full robot orbit, title card.
## Frame 2 — The kit (10–22.5 s)
status: built · src: index.html · exploded view of every part.
## Frame 3 — Step 01 Tub + inserts (22.5–37 s)
status: built
## Frame 4 — Step 02 Four motors (37–75 s)
status: built · tub see-through, collar through the wall, nut spins in.
## Frame 5 — Step 03 Battery cage (75–89 s)
status: built
## Frame 6 — Step 04 Floor boards (89–109 s)
status: built
## Frame 7 — Step 05 Wheels + tyres (109–133 s)
status: built
## Frame 8 — Step 06 Battery (133–143 s)
status: built
## Frame 9 — Step 07 Wooden deck (143–167 s)
status: built
## Frame 10 — Step 08 The arm (167–181 s)
status: built
## Frame 11 — Step 09 Power path (181–205 s)
status: built · wires draw, shell see-through.
## Frame 12 — Step 10 Motors → driver (205–217 s)
status: built
## Frame 13 — Step 11 Signals (217–232 s)
status: built
## Frame 14 — Finale (232–240 s)
status: built · arm STOW → HOME → REACH_450, end card THENAR.IO / THENARLABS.

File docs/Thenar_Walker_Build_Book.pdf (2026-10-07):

# THENAR WALKER

## Build book — RoboReach 2026-27 (Techfest IIT Bombay)

Every printed part with its sizes and every hole (size, position, what screw goes in it), the overall robot dimensions, where each board sits, the assembly steps, wiring, and the full parts list with what the team already has.

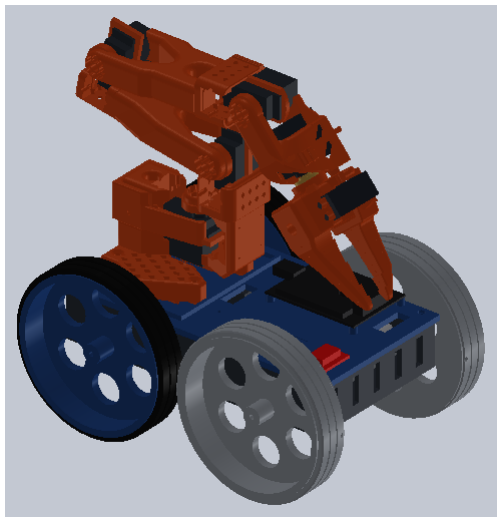
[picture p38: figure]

SolidWorks assembly in the STOW start pose

Section | Page
1 · Overall dimensions | 2
2 · Parts and their sizes | 3
3 · Part drawings with every hole | 4
4 · Layout: where everything sits | 14
5 · Assembly, step by step | 16
6 · Wiring | 17
7 · Bill of materials and status | 18
8 · Print plates and checklist | 19

Two open items change some drawings: (1) the tub motor slots are drawn for a 25 mm motor; the motors bought are 35 mm (6 mm shaft, M8 collar) — the tub will be redrawn once the motor is fully measured. (2) The deck bosses fit the Cytron MDD10A; if the SHIELD-MDD10 is used instead, they move.

THENAR WALKER · RoboReach 2026-27 | Build book: sizes, holes, assembly

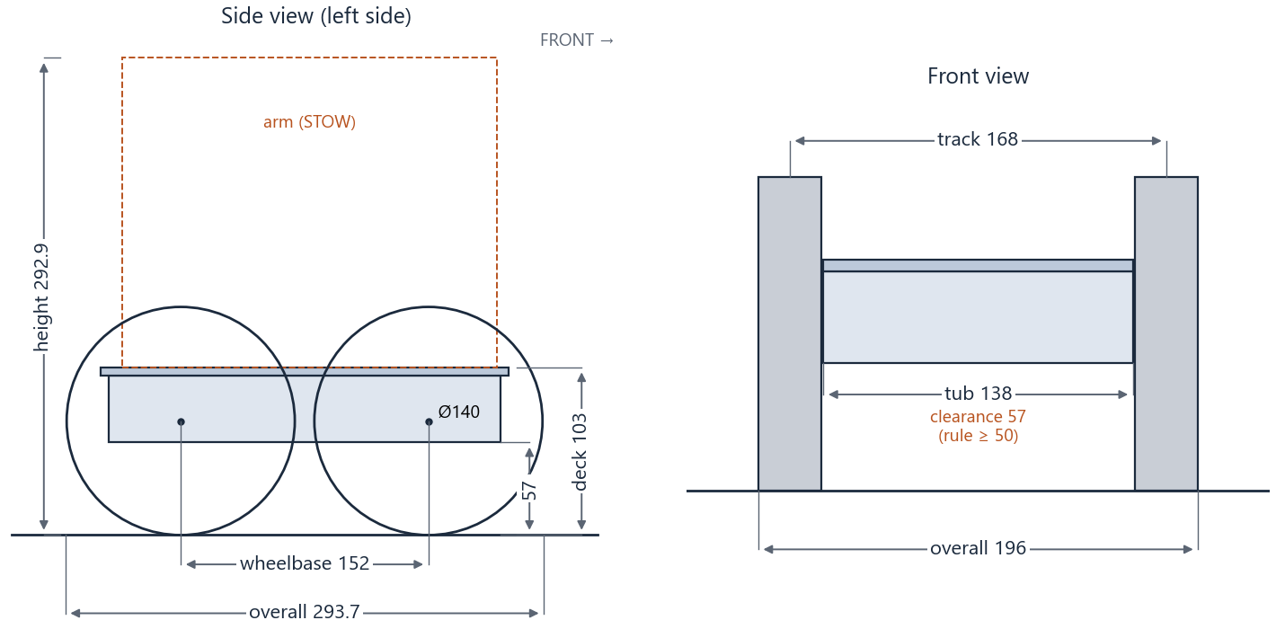
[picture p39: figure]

All sizes in mm. Drawings are not to scale — use the numbers. Generated from the project CAD. | page 2

# 1 · Overall dimensions

Robot in the STOW start pose (from design.py and SolidWorks)

Item | Size | Rule / note
Overall L × W × H (STOW) | 293.7 × 196.0 × 292.9 | must fit 300 × 200 × 300 at the start
Ground clearance (lowest point except wheels) | 57.0 (tub floor) | rule ≥ 50. With the 35 mm motor the motor bottom is ~52.5
Wheels | Ø140 × 28 wide | front: one-piece PETG; rear: PETG hub + TPU tyre
Wheelbase / track | 152 / 168 | axle 70 above the ground
Chassis tub | 240 × 138 × 41 | bottom at 57, top at 98
Deck plate | 250 × 138 × 5 (+ 6 bosses, 4 fence) | top surface at 103
Arm base position | x = −87 from the centre | bolted through 4 of the arm base vent slots
Grasp height (REACH_450) | object centre at 449.6 | rule: object centred at 450
Floor pick (PICK_FLOOR) | grasp centre 25.1 above the ground | 50 mm cube ~254 ahead of the centre
Mass (CAD estimate) | 2.40 kg | arm included
Battery voltage | 11.1 V nominal, 12.6 V full | rule ≤ 24 V DC

All sizes in mm. Drawings are not to scale — use the numbers. Generated from the project CAD. | page 3

# 2 · Parts and their sizes

## Printed parts (PETG unless marked)

Part | Qty | Size (L × W × H) | Key holes | Drawing
RR-01 Chassis tub | 1 | 240 × 138 × 41 | 4 × Ø4 insert bores, motor slots, 20 × Ø2.2 pilots | p. 4–7
RR-02 Deck plate | 1 | 250 × 138 × 11 | 8 × Ø3.4, 4 × Ø2.6, 2 × Ø2.8, 2 slots, kill switch cut-out
p. 8
RR-03 Battery cage | 1 | 128 × 44 × 27 (inside 108 × 36) | 2 × Ø3.4 tabs, 4 × Ø2.6 bar pilots | p. 9
RR-04 Battery bar | 2 | 10 × 44 × 3 | 2 × Ø3.4 | p. 10
RR-05 Rear hub (6 mm) | 2 | Ø131 × 28 (rim Ø128) | Ø6.3 bore, 6 × Ø26, M3 grub | p. 11
RR-07 Front wheel (6 mm) | 2 | Ø140 × 28 | Ø6.3 bore, 6 × Ø26, M3 grub | p. 12
RR-06F Tyre half-strip (TPU) | 4 | 224.3 × 25 × 6 | Ø4.4 key notch, click joint | p. 13

## Bought parts

Part | Size | Mounting | Note

Gear motor 370, plastic gearbox, 12
V ~100 RPM

gearbox Ø35; shaft Ø6 round with cross-hole

| | | M8 threaded collar + 13 mm nut

To measure: collar length, shaft length, gearbox length, can Ø ×
| | | length

Cytron MDD10A Rev2.0 motor driver

84.5 × 62 × ~13 | 4 × Ø3 holes on 78.74 ×
| | | 55.88

deck top, terminals forward

Cytron SHIELD-MDD10 (alternative) | Arduino-Uno shield size (~69 ×
| 54)
Uno hole pattern | measure before use
ESP32-DevKitC 38-pin | 55 × 28 | 2 × M2.5 standoffs, zip tie | under the deck
PCA9685 servo driver | 62.2 × 25.4 | 4 × M2.5 posts | tub floor
6 V buck ≥ 10 A (XL4016 class) | 66 × 48 × 18 | 4 × M2.5 posts | tub floor
MP1584 5 V buck | 22 × 17 | 4 × M2.5 posts | tub rear corner
3S LiPo 2200 mAh, XT60 | max 106 × 34 × 26 | in the cage, 2 bars on top
KCD4 rocker (kill switch) | cut-out 30.2 × 22.2, body 32
| deep
snaps into the deck | front right
MG996R servo (arm, ×6) | 40.7 × 19.7 × 42.9 | arm parts | thenar-arms R3

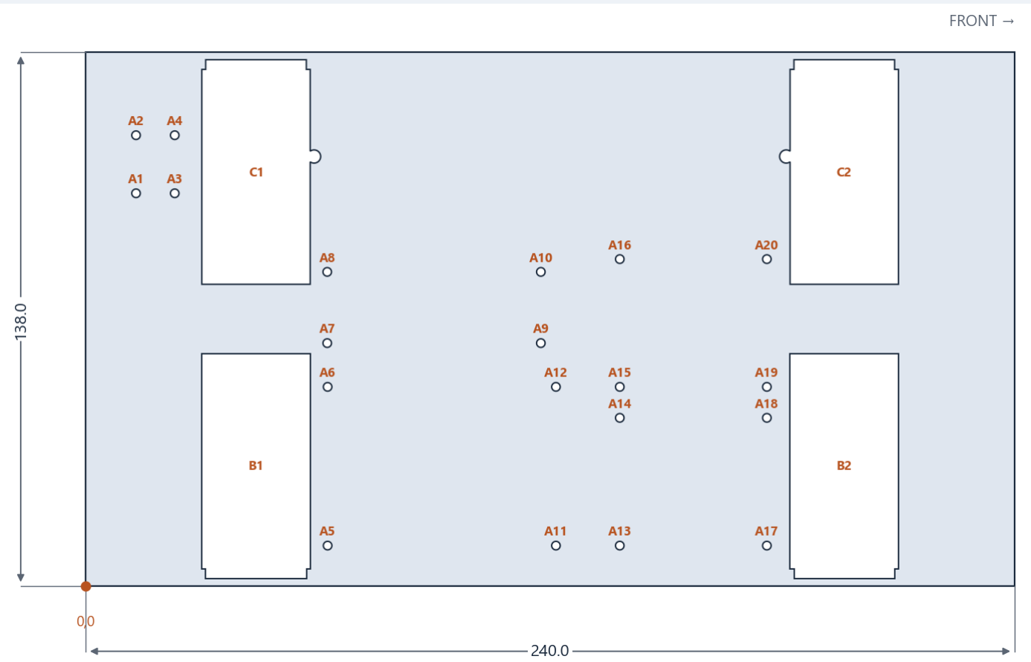
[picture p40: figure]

All sizes in mm. Drawings are not to scale — use the numbers. Generated from the project CAD. | page 4

# 3 · Part drawings with every hole

Each drawing is a slice through the real 3-D part. Holes are lettered by size (A = smallest); the table says what each is for, and the X / Y list gives every hole centre measured from the orange 0,0 corner (or from the centre for wheels). Check a printed part with a caliper against these numbers.

## RR-01 Chassis tub — floor

On hold: the tub is drawn for the 25 mm motor. The motor slots, side-wall holes and floor windows will change for the 35 mm motor, and the battery-cage screw holes (half inside the motor windows, marked C1 / C2 notch) will move inward. Do not print plate 1 until the redesign.

Section of the real part · overall 240.0 × 138.0 mm in this view · hole centres from the 0,0 corner (X to the right, Y up)

ID | Size (mm) | Qty | What it is for
A | Ø2.2 | 20 | Board standoff pilots (Ø6 × 3 posts): M2.5 × 6 self-tapping. 5 V buck, PCA9685, 6 V buck, 2 spare pads.
B | 28.0 × 58.0 | 2 | Motor floor window (motor can drops in)
C | 30.7 × 58.0 | 2 | Motor floor window + half of the battery-cage screw hole
ID | X | Y
A1 | 13.0 | 101.5
A2 | 13.0 | 116.5
A3 | 23.0 | 101.5
A4 | 23.0 | 116.5
A5 | 62.5 | 10.5
A6 | 62.5 | 51.5
A7 | 62.4 | 62.8
A8 | 62.4 | 81.2
ID | X | Y
A9 | 117.6 | 62.8
A10 | 117.6 | 81.2
A11 | 121.5 | 10.5
A12 | 121.5 | 51.5
A13 | 138.0 | 10.5
A14 | 138.0 | 43.5
A15 | 138.0 | 51.5
A16 | 138.0 | 84.5
ID | X | Y
A17 | 176.0 | 10.5
A18 | 176.0 | 43.5
A19 | 176.0 | 51.5
A20 | 176.0 | 84.5
B1 | 44.0 | 31.1
B2 | 196.0 | 31.1
C1 | 44.1 | 106.9
C2 | 195.9 | 106.9
- Section through the 3 mm floor. Board standoff pilots (Ø2.2) are 1 mm deep into the floor, under 3 mm tall Ø6 posts.
- The 4 big cut-outs at the corners are the motor floor windows.

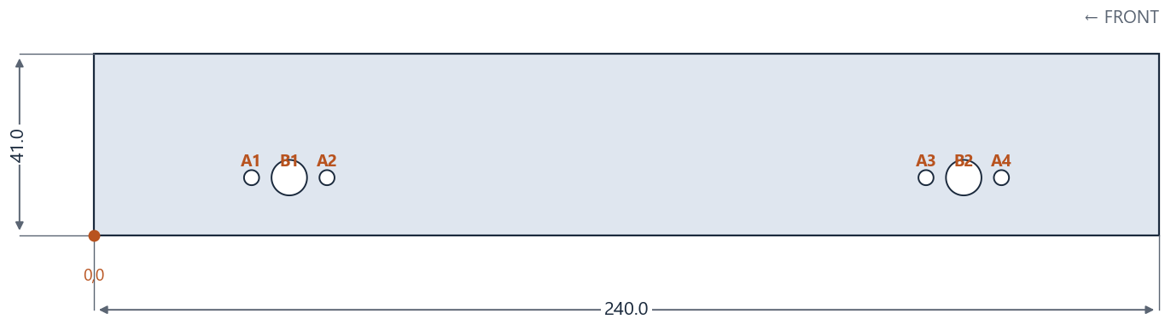
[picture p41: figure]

All sizes in mm. Drawings are not to scale — use the numbers. Generated from the project CAD. | page 5

## RR-01 Chassis tub — side wall

Section of the real part · overall 240.0 × 41.0 mm in this view · hole centres from the 0,0 corner (X to the right, Y up)

ID | Size (mm) | Qty | What it is for
A | Ø3.4 | 4 | M3 × 6: gearbox face to wall (2 per motor, 17 apart)
B | Ø8.0 | 2 | Motor shaft + gearbox boss
ID | X | Y
A1 | 35.5 | 13.0
A2 | 52.5 | 13.0
A3 | 187.5 | 13.0
A4 | 204.5 | 13.0
B1 | 44.0 | 13.0
B2 | 196.0 | 13.0
- Motor slots: 26 mm wide U-slots, round top centred on the axle (13 mm above the tub bottom = 70 mm above the ground), open at the bottom.
- Per motor: Ø8 shaft/boss hole + 2 × Ø3.4 (M3) holes 17 mm apart. The right wall is the mirror image.
- Sized for the 25 mm motor — will change for the 35 mm motor.

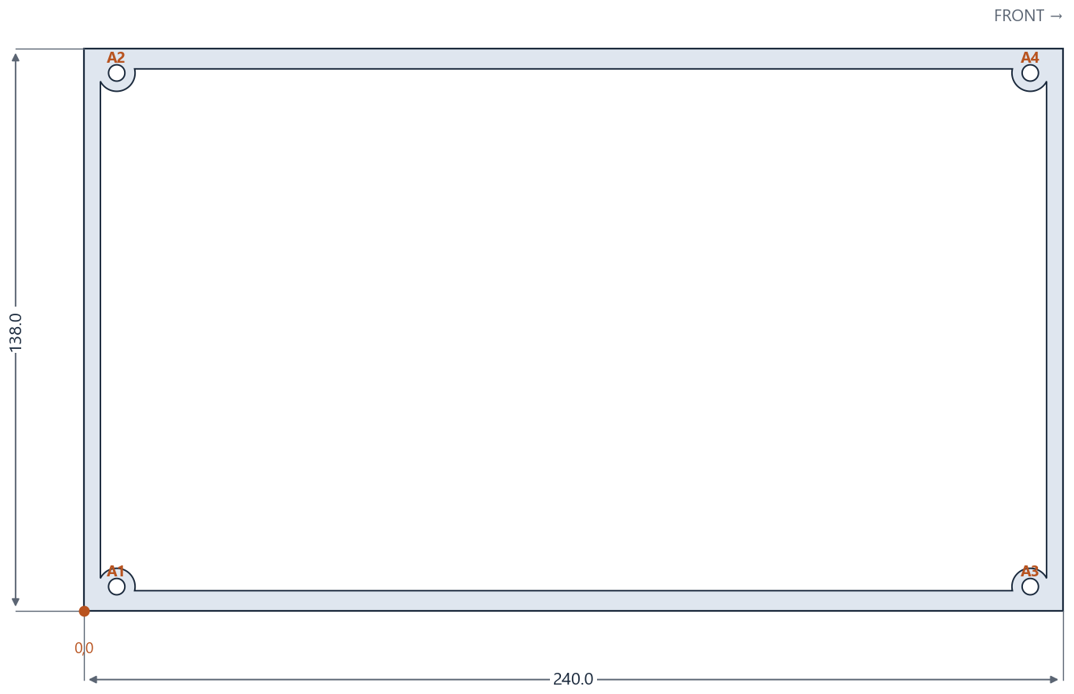
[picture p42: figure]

All sizes in mm. Drawings are not to scale — use the numbers. Generated from the project CAD. | page 6

## RR-01 Chassis tub — top (insert columns)

Section of the real part · overall 240.0 × 138.0 mm in this view · hole centres from the 0,0 corner (X to the right, Y up)

ID | Size (mm) | Qty | What it is for
A | Ø4.0 | 4 | M3 heat-set insert bore, 8 deep
ID | X | Y
A1 | 8.0 | 6.0
A2 | 8.0 | 132.0
A3 | 232.0 | 6.0
A4 | 232.0 | 132.0
- Corner columns Ø9 with Ø4.0 bores, 8 mm deep: melt in the M3 heat-set inserts.

## RR-01 Chassis tub — front wall

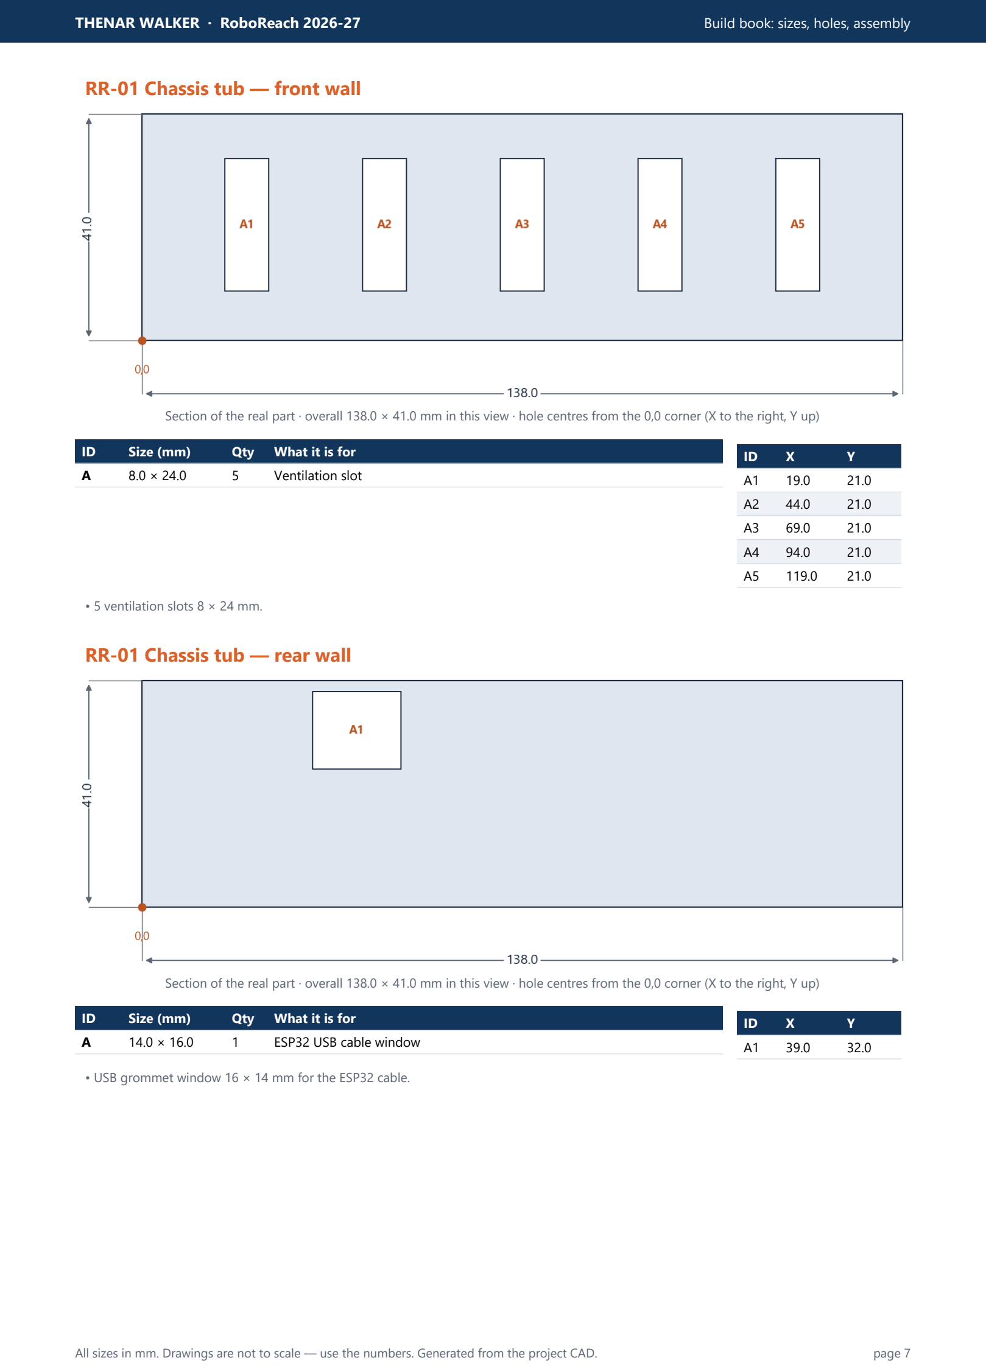
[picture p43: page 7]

All sizes in mm. Drawings are not to scale — use the numbers. Generated from the project CAD. | page 7

Section of the real part · overall 138.0 × 41.0 mm in this view · hole centres from the 0,0 corner (X to the right, Y up)

ID | Size (mm) | Qty | What it is for
A | 8.0 × 24.0 | 5 | Ventilation slot
ID | X | Y
A1 | 19.0 | 21.0
A2 | 44.0 | 21.0
A3 | 69.0 | 21.0
A4 | 94.0 | 21.0
A5 | 119.0 | 21.0
- 5 ventilation slots 8 × 24 mm.

## RR-01 Chassis tub — rear wall

Section of the real part · overall 138.0 × 41.0 mm in this view · hole centres from the 0,0 corner (X to the right, Y up)

ID | Size (mm) | Qty | What it is for
A | 14.0 × 16.0 | 1 | ESP32 USB cable window
ID | X | Y
A1 | 39.0 | 32.0
- USB grommet window 16 × 14 mm for the ESP32 cable.

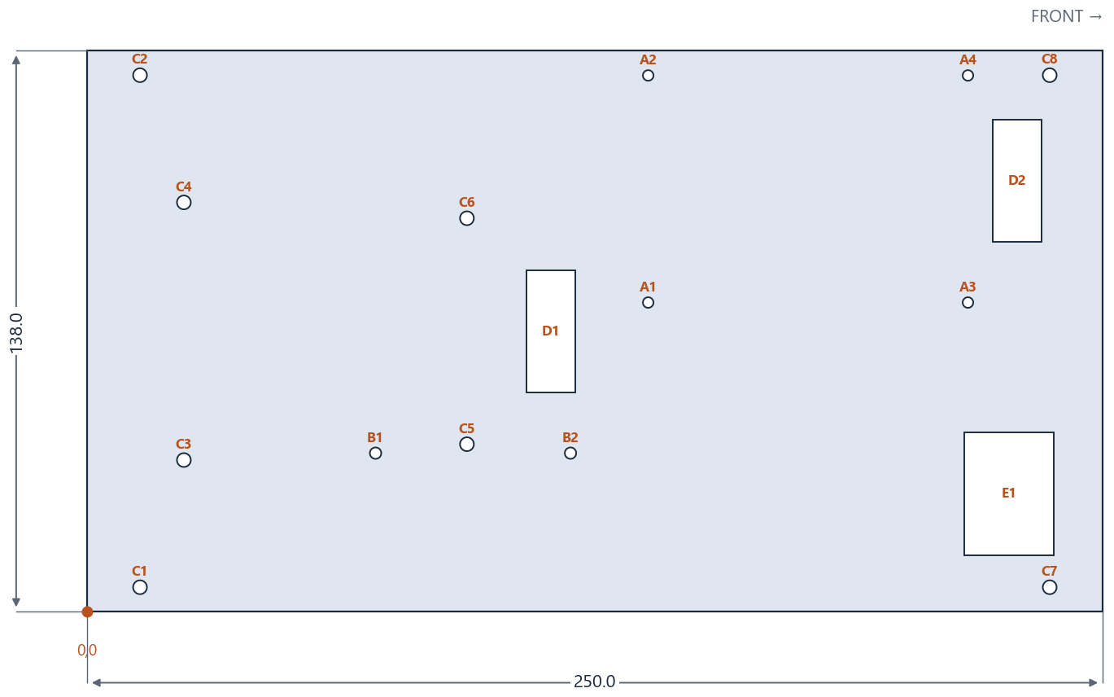
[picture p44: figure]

All sizes in mm. Drawings are not to scale — use the numbers. Generated from the project CAD. | page 8

## RR-02 Deck plate

Section of the real part · overall 250.0 × 138.0 mm in this view · hole centres from the 0,0 corner (X to the right, Y up)

ID | Size (mm) | Qty | What it is for
A | Ø2.6 | 4 | Motor driver MDD10A: M3 × 10 self-tapping (pilot in a Ø7 × 6 mm boss)
B | Ø2.8 | 2 | ESP32: M2.5 × 10 brass standoffs (hangs under the deck)
C | Ø3.4 | 8 | 4 corners: M3 × 10 deck → tub inserts (counterbored). Inner 4: arm base M3 × 20 + washer + nyloc
D | 12.0 × 30.0 | 2 | Slots: servo + signal wires (by the arm), motor + power wires (in front of the driver)
E | 22.2 × 30.2 | 1 | Kill switch cut-out (KCD4 snaps in)
ID | X | Y
A1 | 138.1 | 76.1
A2 | 138.1 | 131.9
A3 | 216.9 | 76.1
A4 | 216.9 | 131.9
B1 | 71.0 | 39.0
B2 | 119.0 | 39.0
ID | X | Y
C1 | 13.0 | 6.0
C2 | 13.0 | 132.0
C3 | 23.8 | 37.3
C4 | 23.8 | 100.7
C5 | 93.5 | 41.2
C6 | 93.5 | 96.8
ID | X | Y
C7 | 237.0 | 6.0
C8 | 237.0 | 132.0
D1 | 114.2 | 69.0
D2 | 229.0 | 106.0
E1 | 227.0 | 29.0
- Ø3.4 corner holes, counterbored Ø6.5 × 2.5 deep on top: deck → tub, M3 × 10.
- Arm base: 4 × Ø3.4 through the arm vent slots, M3 × 20 + nyloc under the deck.
- MDD10A: 4 × Ø2.6 pilots in Ø7 × 6 mm bosses on top, 78.74 × 55.88 apart (M3 × 10 self-tapping).
- ESP32: 2 × Ø2.8 for the M2.5 brass standoffs.

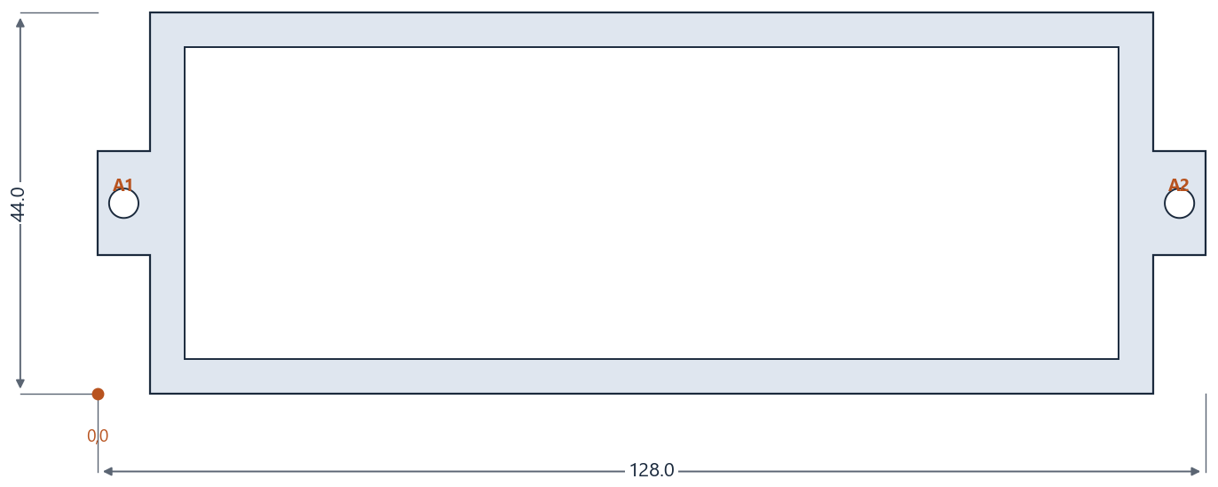
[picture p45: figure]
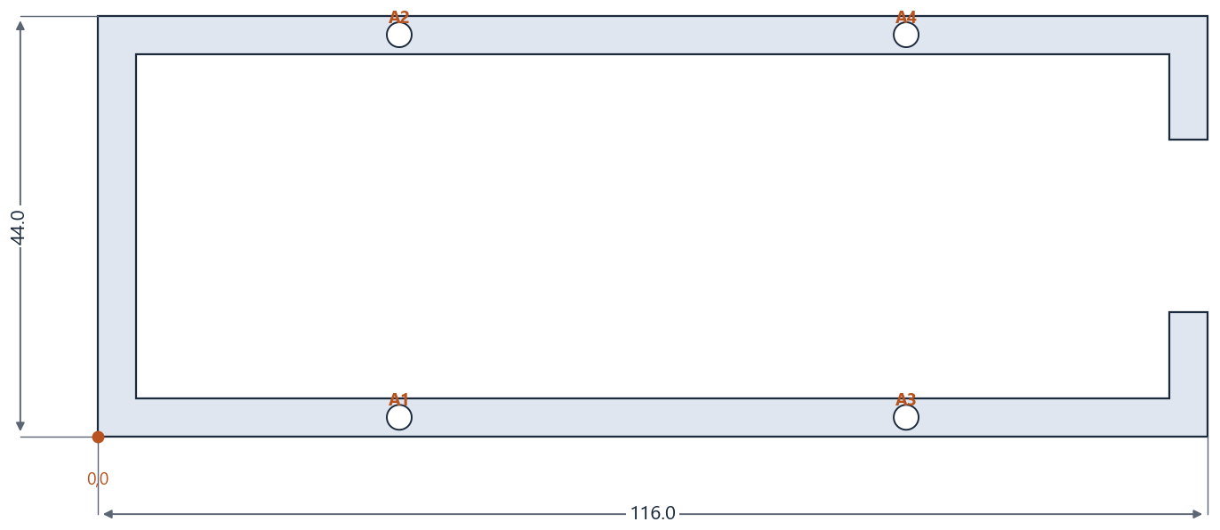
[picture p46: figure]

All sizes in mm. Drawings are not to scale — use the numbers. Generated from the project CAD. | page 9

## RR-03 Battery cage — base

Section of the real part · overall 128.0 × 44.0 mm in this view · hole centres from the 0,0 corner (X to the right, Y up)

ID | Size (mm) | Qty | What it is for
A | Ø3.4 | 2 | M3 × 8 + nyloc through the tub floor
ID | X | Y
A1 | 3.0 | 22.0
A2 | 125.0 | 22.0
- Inside 108 × 36 mm (battery max 106 × 34 × 26). Tabs: 2 × Ø3.4 for M3 × 8 + nyloc through the tub floor.

## RR-03 Battery cage — top

Section of the real part · overall 116.0 × 44.0 mm in this view · hole centres from the 0,0 corner (X to the right, Y up)

ID | Size (mm) | Qty | What it is for
A | Ø2.6 | 4 | M3 × 8 self-tapping for the bars
ID | X | Y
A1 | 31.5 | 2.0
A2 | 31.5 | 42.0
A3 | 84.5 | 2.0
A4 | 84.5 | 42.0
- 4 × Ø2.6 pilots, 8 mm deep: M3 × 8 self-tapping for the two bars.

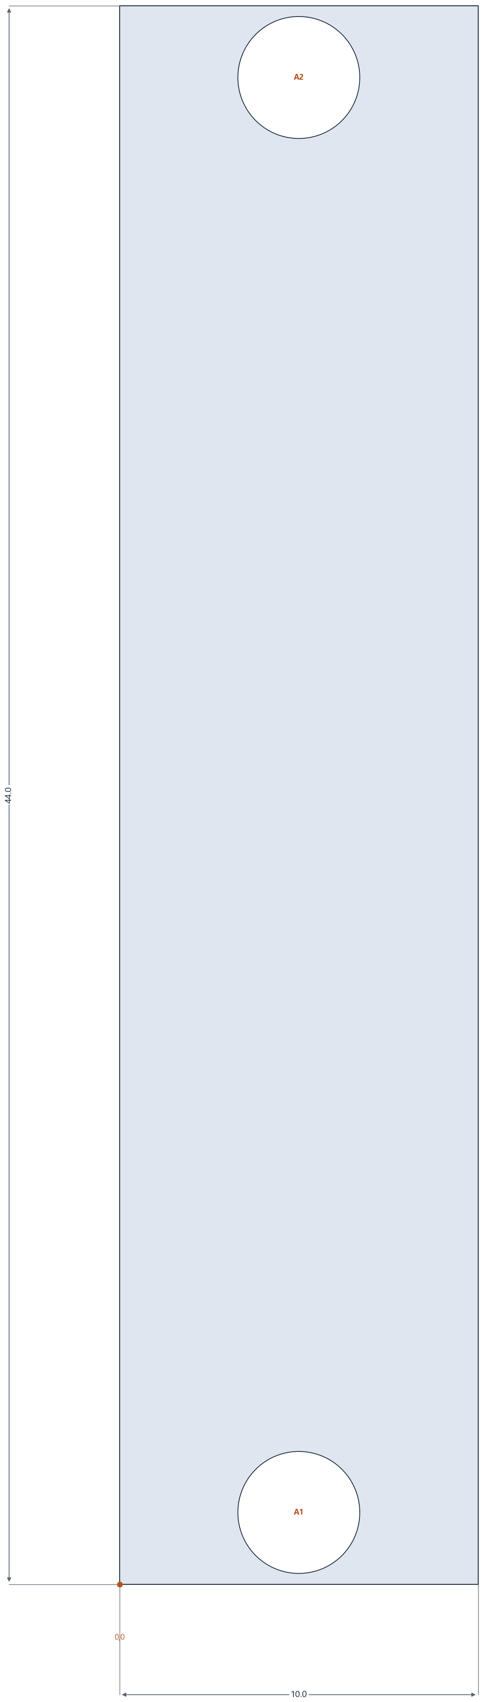
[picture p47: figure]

All sizes in mm. Drawings are not to scale — use the numbers. Generated from the project CAD. | page 10

## RR-04 Battery bar (× 2)

Section of the real part · overall 10.0 × 44.0 mm in this view · hole centres from the 0,0 corner (X to the right, Y up)

ID | Size (mm) | Qty | What it is for
A | Ø3.4 | 2 | M3 × 8 clearance (into the cage bosses)
ID | X | Y
A1 | 5.0 | 2.0
A2 | 5.0 | 42.0
- 3 mm thick.

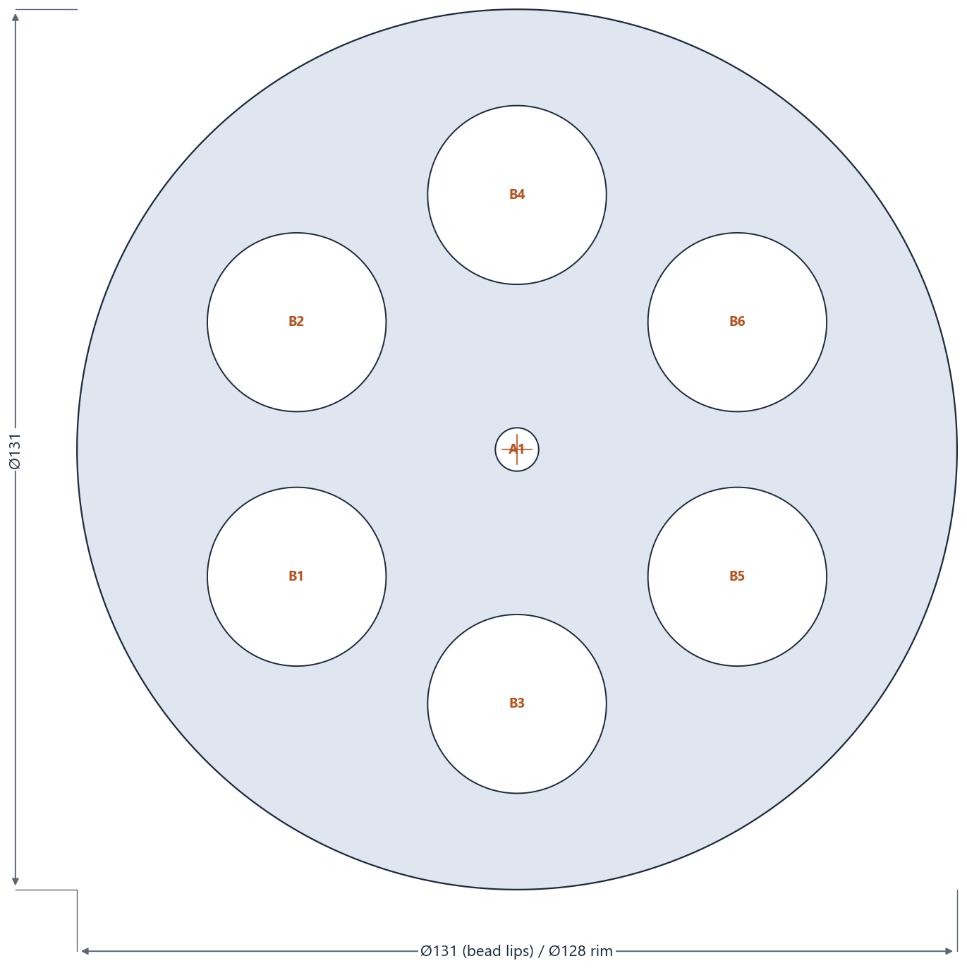
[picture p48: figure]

All sizes in mm. Drawings are not to scale — use the numbers. Generated from the project CAD. | page 11

## RR-05 Rear wheel hub (6 mm shaft)

Section of the real part · overall 128.0 × 128.0 mm in this view · hole centres from the wheel centre (X to the right, Y up)

ID | Size (mm) | Qty | What it is for
A | Ø6.3 | 1 | Motor shaft (6 mm round)
B | Ø26.0 | 6 | Lightening holes
ID | X | Y
A1 | 0.0 | -0.0
B1 | -32.0 | -18.5
B2 | -32.0 | 18.5
B3 | 0.0 | -37.0
B4 | -0.0 | 37.0
B5 | 32.0 | -18.5
B6 | 32.0 | 18.5
- Positions from the wheel centre. Rim Ø128 between two bead lips Ø131; width 28.
- Bore Ø6.3 round. M3 grub screw: Ø2.6 radial hole 3.6 mm from the inner face, hex-key access Ø3.8 through the rim.

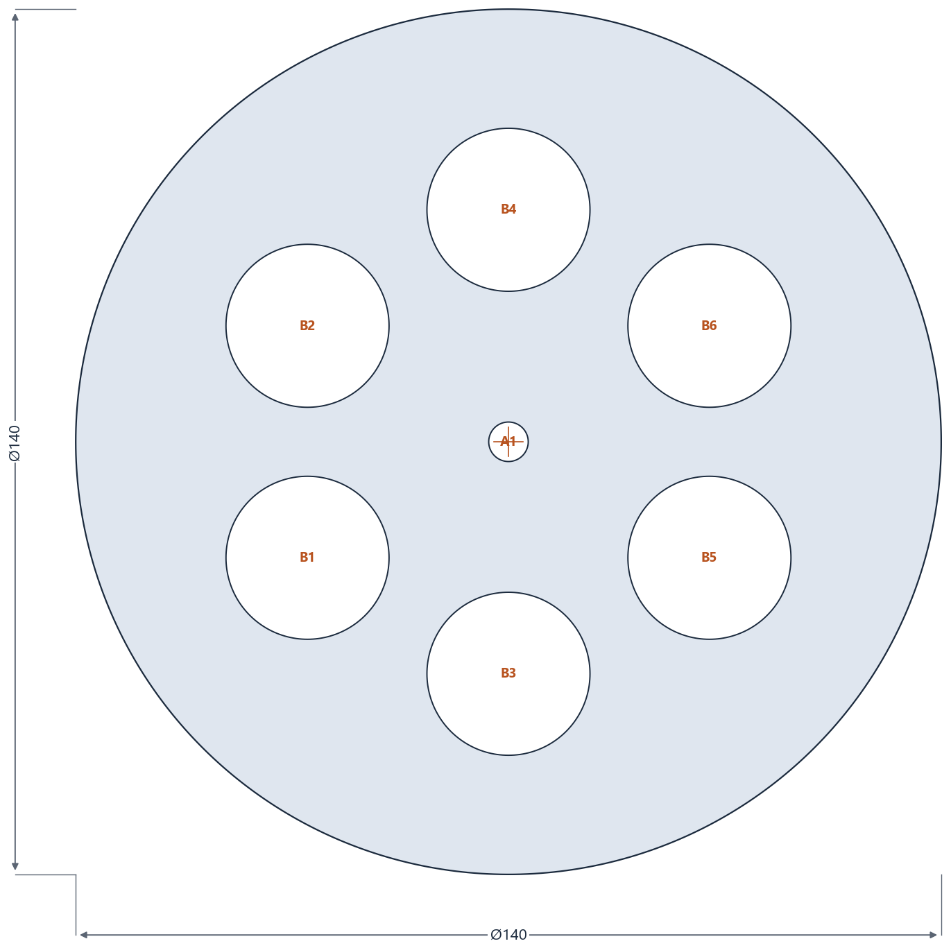
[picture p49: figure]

All sizes in mm. Drawings are not to scale — use the numbers. Generated from the project CAD. | page 12

## RR-07 Front wheel (6 mm shaft)

Section of the real part · overall 138.0 × 138.0 mm in this view · hole centres from the wheel centre (X to the right, Y up)

ID | Size (mm) | Qty | What it is for
A | Ø6.3 | 1 | Motor shaft (6 mm round)
B | Ø26.0 | 6 | Lightening holes
ID | X | Y
A1 | 0.0 | -0.0
B1 | -32.0 | -18.5
B2 | -32.0 | 18.5
B3 | 0.0 | -37.0
B4 | -0.0 | 37.0
B5 | 32.0 | -18.5
B6 | 32.0 | 18.5
- Positions from the wheel centre. Ø140 one-piece, width 28, tread with 2 grooves.
- Bore Ø6.3 round. Grub screw as the rear hub; the key access hole goes through the tread.

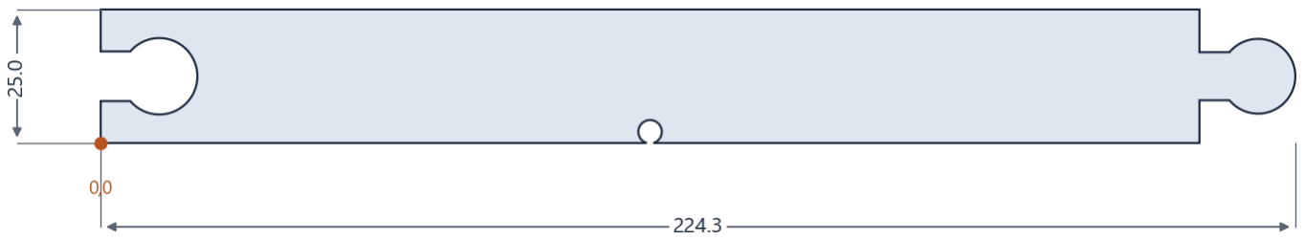
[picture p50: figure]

All sizes in mm. Drawings are not to scale — use the numbers. Generated from the project CAD. | page 13

## RR-06F TPU tyre half-strip

Section of the real part · overall 224.3 × 25.0 mm in this view · hole centres from the 0,0 corner (X to the right, Y up)
- 6 mm thick, 25 mm wide, 224.3 mm long including the knob. Two halves make one tyre (412.6 mm, 2 % shorter than the hub).
- Ø4.4 key hole sits over the hub grub screw (edge with the hole toward the robot).

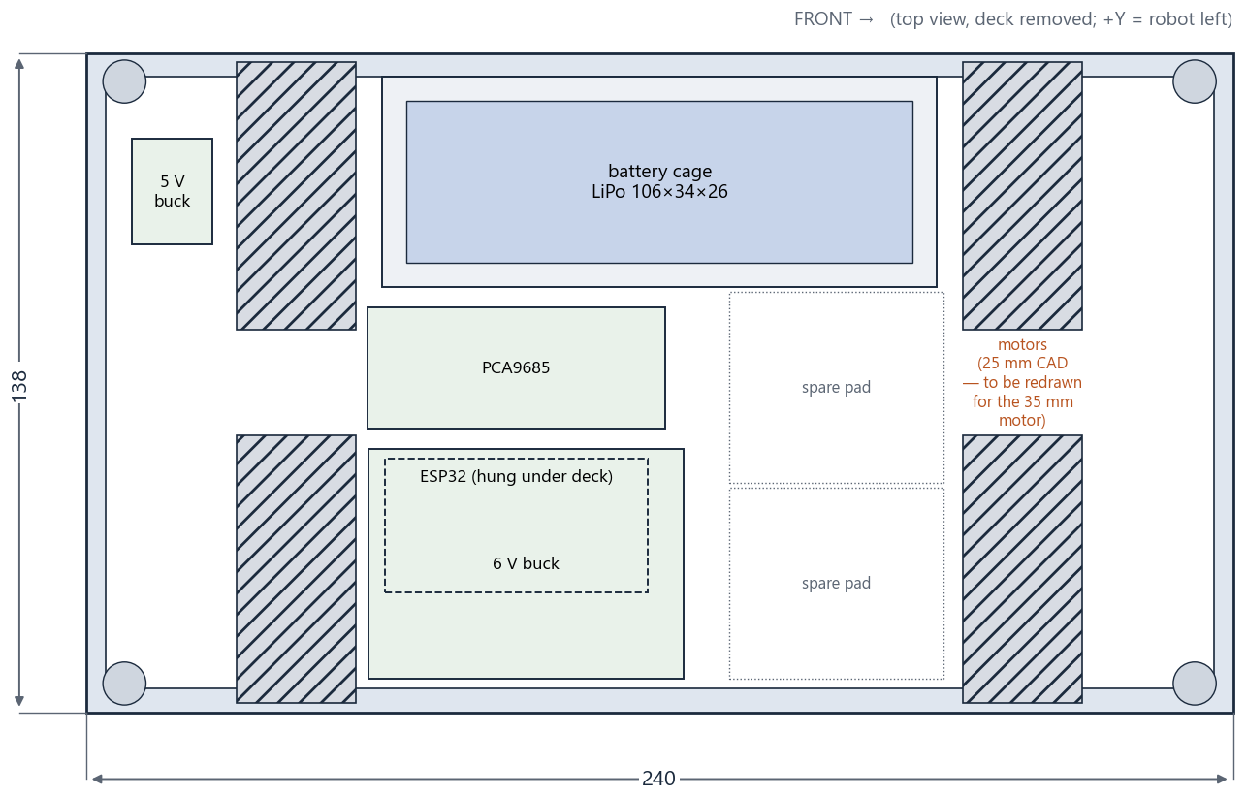
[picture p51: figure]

All sizes in mm. Drawings are not to scale — use the numbers. Generated from the project CAD. | page 14

# 4 · Layout: where everything sits

## Tub floor (deck removed)

Top view. Positions are board centres from the tub centre; +X forward, +Y to the robot left.
Item | Centre X | Centre Y | Size | Mounted on
6 V buck | -28.0 | -38.0 | 66 × 48 | floor posts (3 mm)
Motor driver MDD10A | 52.5 | 35.0 | 84.5 × 62 | deck top (6 mm bosses)
PCA9685 | -30.0 | 3.0 | 62.2 × 25.4 | floor posts (3 mm)
5 V buck (MP1584) | -102.0 | 40.0 | 22 × 17 (turned 90°) | floor posts (3 mm)
ESP32 | -30.0 | -30.0 | 55 × 28 | under the deck (10 mm standoffs)
Battery (in the cage) | 0.0 | 42.0 | 106 × 34 | cage on the floor
Kill switch | 102.0 | -40.0 | 30.2 × 22.2 cut-out | deck
Arm base origin | -87.0 | 0.0 | fence inside 88 × 112 | deck

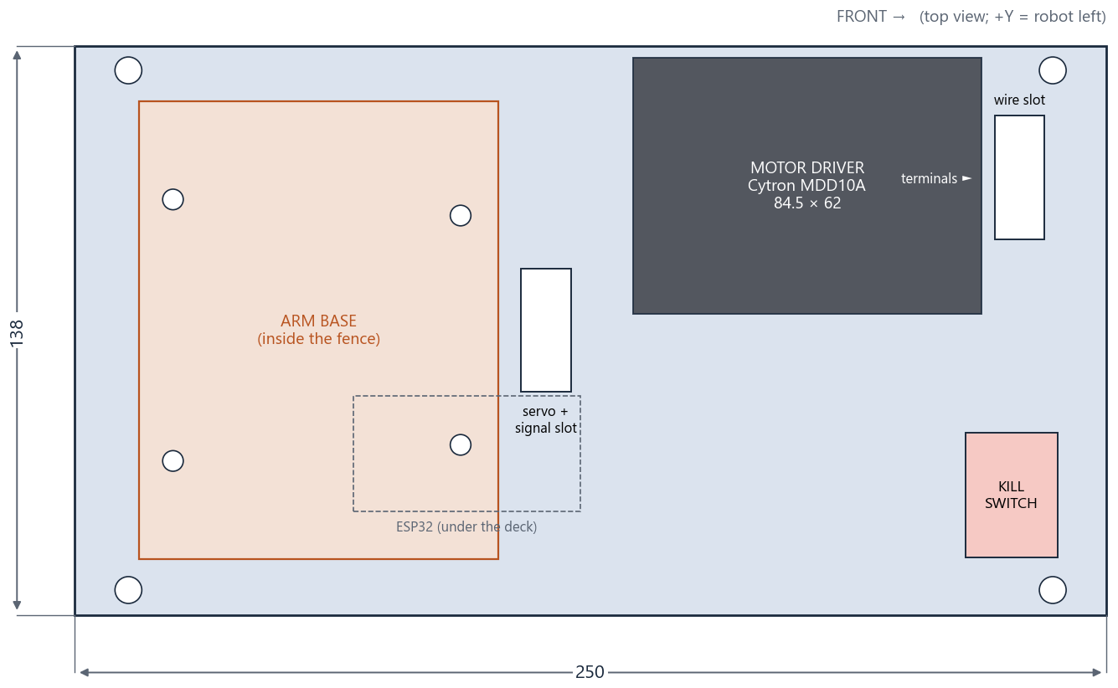
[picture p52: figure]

All sizes in mm. Drawings are not to scale — use the numbers. Generated from the project CAD. | page 15

## Deck top

Top view of the deck. The driver terminals face forward over the wire slot. Motor wheels: front-left, rear-left, front-right, rear-right motors sit at X = ±76 (wheelbase 152), axle 70 above the ground, shafts pointing outward through the side walls.

All sizes in mm. Drawings are not to scale — use the numbers. Generated from the project CAD. | page 16

# 5 · Assembly, step by step

0 · Before you start | Caliper, the motor, the drivers
- Measure one motor: collar length, shaft length past the collar, gearbox length, can Ø × length. The tub is redrawn from these.
- Decide the driver: MDD10A (deck ready) or SHIELD-MDD10 (deck bosses move).
- Bottle test done: one motor lifted 750 ml at 7 cm (≥ ~5.2 kg·cm), enough for the course.
1 · Print | P1S, ~0.8 kg PETG, ~85 g TPU per tyre plate
- PETG: plate 1 (tub, cage, bars — after the redesign), plate 2 (deck), plates 3 + 4b (wheels). TPU: plate 5F (tyre strips) ×1, ×2 for spares.
- 0.2 mm layers, 4 walls, 30 % gyroid (TPU: 3 walls, 20 %), no supports. TPU from the external spool, not the AMS.
2 · Clean up the prints | 6 mm drill, M3 tap (optional)
- Run a 6 mm drill through each wheel bore by hand; drill the 2 older 4 mm-bore wheels out to 6 mm.
- Tap or self-thread the Ø2.6 grub holes with an M3 grub screw.
- Check holes against the drawings (section 3) with a caliper.
3 · Tub | 4 inserts, 2 × M3×8 + nyloc, ~12 × M2.5×6, motor mounts
- Melt 4 × M3 heat-set inserts into the corner bores (Ø4.0, 8 deep).
- Screw the battery cage to the floor: 2 × M3 × 8 + nyloc from below.
- Mount the 4 motors in the side walls, shafts out (new mount for the 35 mm motor). Solder leads first.
- Screw the 6 V buck, PCA9685 and 5 V buck to their floor posts (M2.5 × 6 self-tapping).
- Set the 6 V buck to 6.0 V and the 5 V buck to 5.0 V with a multimeter, before connecting anything.
4 · Wheels and tyres | 4 × M3×5 grub, superglue
- Rear: click two TPU half-strips together, superglue the joint, wrap around a rear hub between the lips (grooves out, notch over the grub screw), pull the second joint closed and glue.
- Push each wheel onto its shaft ~1 mm off the wall; turn it so the grub screw lines up with the shaft cross-hole; tighten the M3 × 5 grub.
- Front wheels (hard, one piece) at the front, TPU-tyred wheels at the rear. Spin each wheel by hand: no rubbing.
5 · Deck | 2 standoffs, 4 × M3×10 self-tap, zip ties
- Screw 2 × M2.5 × 10 brass standoffs under the deck, zip-tie the ESP32 to them (USB toward the rear window).
- Snap the kill switch into its cut-out (front right) and wire it in series with battery +.
- Motor driver on the 4 bosses (M3 × 10 self-tapping), blue terminals facing forward.
- Route: servo leads + 5 driver signal wires up through the slot by the arm; motor + power wires up through the slot in front of the driver.
6 · Close up and fit the arm | 4 × M3×8 self-tap, 4 × M3×10, 4 × M3×20 + nyloc
- Battery into the cage, lead out of the front window, screw on the two bars (M3 × 8 self-tapping).
- Deck onto the tub: 4 × M3 × 10 into the inserts.
- Arm base inside the fence, 4 × M3 × 20 + washers through the base vent slots, nyloc nuts under the deck.
- Servos J1…J6 into PCA9685 channels 0…5.
7 · Firmware and first power-up | USB cable, multimeter
- python firmware/tools/new_key.py "Team Name" → flash thenar_walker_bot (robot) and thenar_walker_controller (leader).
- Wheels off the ground, kill switch in reach. Use the driver test buttons (M1A/M1B/M2A/M2B) first.
- Joystick check: if a whole side runs backwards swap that side's two driver wires.
- Calibrate the servos (calibration.h), set FOLLOWER_CALIBRATED = true, reflash.
- Failsafe test: switch the controller off while holding a cube → wheels stop, arm freezes, gripper holds.

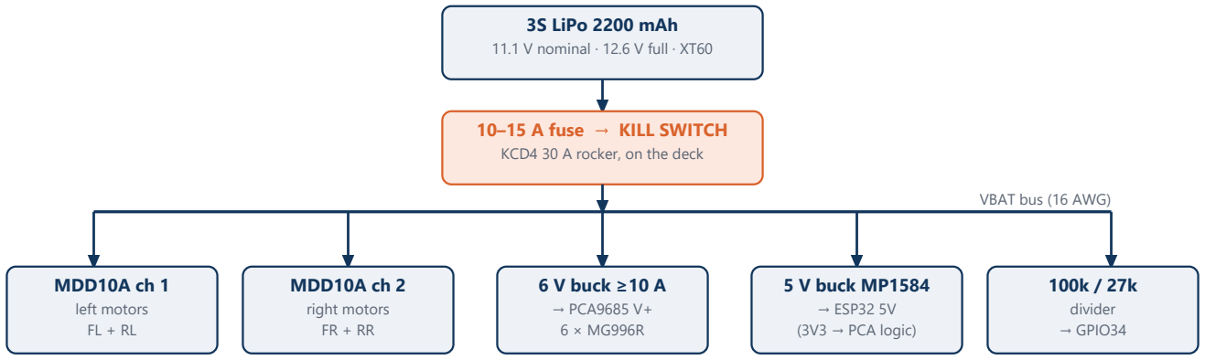
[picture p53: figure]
3S LiPo 2200 mAh; 11.1 V nominal · 12.6 V full · XT60; 10–15 A fuse → KILL SWITCH; KCD4 30 A rocker, on the deck; VBAT bus (16 AWG); MDD10A ch 1; left motors; MDD10A ch 2; right motors; 6 V buck ≥10 A; → PCA9685 V+; 5 V buck MP1584; → ESP32 5V (3V3 → PCA logic); divider; → GPIO34

All sizes in mm. Drawings are not to scale — use the numbers. Generated from the project CAD. | page 17

# 6 · Wiring

All grounds common. Every voltage on the robot ≤ 12.6 V (rule: ≤ 24 V DC). Kill switch is before everything → it shuts the whole robot down (rule).

Motors: both left motors in parallel on channel 1, both right motors on channel 2 — same wire of each motor into the same terminal.

ESP32 pin | Signal | MDD10A (white 5-pin plug) | SHIELD-MDD10 (jumper-selected)
GPIO25 | left speed | PWM1 (pin 4) | PWM1 pin, e.g. D3
GPIO26 | left direction | DIR1 (pin 5) | DIR1 pin, e.g. D2
GPIO16 | right speed | PWM2 (pin 2) | PWM2 pin, e.g. D6
GPIO17 | right direction | DIR2 (pin 3) | DIR2 pin, e.g. D7
GND | ground | GND (pin 1) | any GND
GPIO21 / 22 | I²C | PCA9685 SDA / SCL
GPIO13 | servo enable | PCA9685 OE
GPIO34 | battery sense | 100 kΩ / 27 kΩ divider
GPIO2 | status LED | on-board | solid = ACTIVE

10 kΩ from PWM1 to GND and from PWM2 to GND (no twitch while the ESP32 boots). Fuse 10 A, close to the XT60. Kill switch before everything. Never power the servos from the ESP32 or USB.

All sizes in mm. Drawings are not to scale — use the numbers. Generated from the project CAD. | page 18

# 7 · Bill of materials and status

Have = bought / built. To buy = still needed. Confirm = not reported yet. Decide = two options, only one needed.
Part | Qty | Spec | Status
370 gear motor, plastic gearbox, 12 V ~100 RPM | 4 (+1) | Ø35 gearbox, 6 mm shaft, M8 collar; bottle test passed | Have
M3 × 5 cup-point grub screw | 4 | wheel → shaft | To buy
22 AWG silicone wire red + black | 2 m each | motor leads | Confirm
Cytron MDD10A Rev2.0 | 1 | dual 10 A, PWM + DIR | Decide · have
Cytron SHIELD-MDD10 | 1 | same driver as an Arduino shield | Decide · have
10 kΩ resistor | 2 | PWM pull-downs | To buy
3S LiPo 2200 mAh 30C XT60 | 1 (+1) | max 106 × 34 × 26 | Confirm
LiPo balance charger + safe bag | 1 | 3S balance | Confirm
XT60 pair | 2 | | Have
Glass fuse holder 5 × 20 + 10 A fuse | 1 | inline at the XT60 | Have
LiPo cell tester / buzzer | 1 | on the balance lead | Have
KCD4 rocker 16 A+ (kill switch) | 1 | cut-out 30.2 × 22.2 | Confirm
6 V buck ≥ 10 A | 1 | servo rail | Confirm
MP1584 5 V buck | 1 | ESP32 supply | Confirm
16 AWG silicone wire red + black | 1 m each | power | Confirm
100 kΩ + 27 kΩ resistors | 1 each | battery sense | To buy
ESP32-DevKitC 38-pin | 1 | robot | Confirm
PCA9685 | 1 | servo driver | Confirm
Jumper wires, servo extensions, heat-shrink, zip ties | 1 lot | | Confirm
thenar-arms follower R3 (6 × MG996R) | 1 | the arm | Have
thenar-arms L1 leader (controller) | 1 | | Have
Joystick module, ENABLE toggle, SPEED button, power bank | 1 each | controller add-ons | Confirm
M3 heat-set inserts | 4 | tub corners | Confirm
M3 × 10 socket screws | 4 | deck → tub | Confirm
M3 × 10 self-tapping screws | 4 | driver → deck | To buy
M3 × 8 screws + nyloc | 2 + 2 | cage → floor | Confirm
M3 × 8 self-tapping screws | 4 | bars → cage | Confirm
M3 × 20 screws + washers + nyloc | 4 | arm → deck | Confirm
M2.5 × 10 brass standoffs + M2.5 × 6 screws | 2 + 2 | ESP32 | Confirm
M2.5 × 6 self-tapping screws | ~12 | boards → floor | Confirm
Superglue (CA) | 1 | tyre strip joints | To buy
Plate 1: tub + cage + bars | 1 | PETG | On hold
Plate 2: deck | 1 | PETG | Ready
Plate 3: front wheel + rear hub | 1 | PETG (drill to 6 mm) | Printed
Plate 4b: front wheel + rear hub, 6 mm | 1 | PETG | Printed
Plate 5F: 4 TPU strips = 2 tyres | 1 (+1 spare) | TPU 95A | Printing
25GA-370 motor, MDD3A, TB6612, white plastic wheel | – | earlier plan / unsuitable | Not used

All sizes in mm. Drawings are not to scale — use the numbers. Generated from the project CAD. | page 19

# 8 · Print plates and checklist

Plate | Parts | Material | Time | Filament | Status
1 | tub, cage, 2 bars | PETG | ~7.1 h | ~259 g | On hold
2 | deck | PETG | 3 h 27 min | 117 g | Ready
3 | front wheel + rear hub (4 mm) | PETG | 6 h 08 min | 202 g | Printed
4b | front wheel + rear hub (6 mm) | PETG | 6 h 07 min | 202 g | Printed
5F | 4 tyre strips = 2 tyres | TPU 95A | 5 h 40 min | 84 g | Printing
PETG: 0.2 mm, 4 walls, 30 % gyroid, textured PEI, no supports. TPU: 3 walls, 20 %, external spool, dried. Sliced files: cad/print/sliced/.

Before every run

Battery ≥ 11.4 V (controller shows batt) |
Kill switch reachable and working |
team_config.h generated (not the example) |
Arm folded to STOW, robot inside 300 × 200 × 300 |
All 4 grub screws tight, tyre joints intact |
Failsafe test: controller off → robot stops, gripper holds |

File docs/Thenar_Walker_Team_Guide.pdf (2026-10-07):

# THENAR WALKER

## Mobile robot arm for RoboReach — Techfest IIT Bombay 2026-27

Team build guide: what we are building, what to buy, how to wire, flash, build and test it.

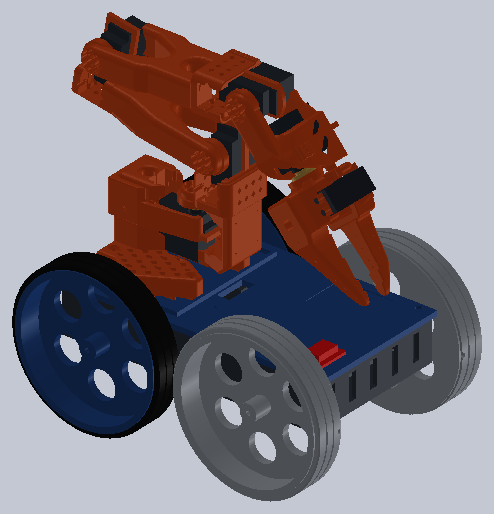
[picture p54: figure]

The robot folded in its start pose (STOW) — SolidWorks render

| Rule | Ours (measured)
Start size | ≤ 300 × 200 × 300 mm | 293.7 × 196.0 × 292.9 mm
Ground clearance | ≥ 50 mm | 57 mm
Grasp object centred at | 450 mm | 449.6 mm
Voltage | ≤ 24 V DC | 12.6 V max (3S LiPo)
Mass | — | 2.39 kg
Drive | — | 4 × 25GA-370 12 V 60 RPM, Ø140 mm wheels, ~0.34 m/s
Full course in simulation | — | pick → ramp → bridge → speed breakers → place: PASS

Contents — 2 Rules · 3 Robot at a glance · 4 The arm · 5 Drive & turning · 6–7 Shopping list · 8 Wiring · 9 Firmware & safety · 10 Build guide · 11 Verified in SolidWorks · 12 Simulated run + team checklist

THENAR WALKER · RoboReach 2026-27 | Team build guide

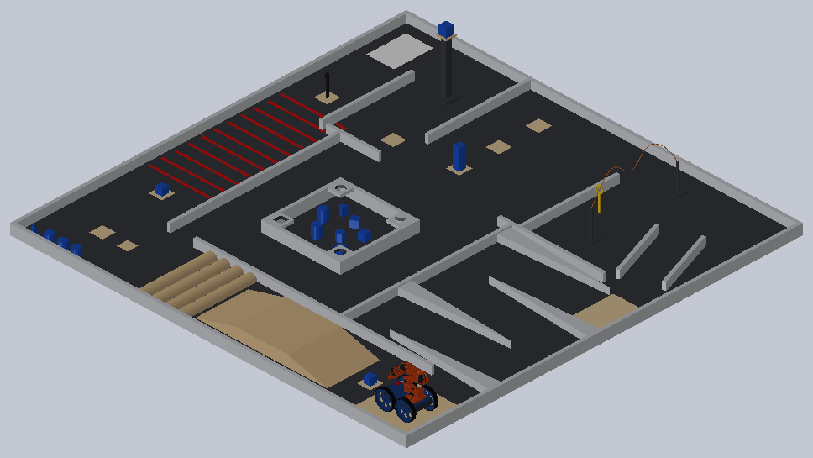
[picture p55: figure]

Everything here is generated from the project files (CAD + simulation). Nothing has been built or powered yet. | 2 / 12

# The challenge and the rules that shape the robot

RoboReach: a manually controlled, wireless robot with an arm. One operator, 7 minutes, 15 obstacles/tasks on a 3 × 3 m arena. Points + time bonus (300 − time, max 100) − penalties. Max 870 + 100.

## Rules that decide the design

Rule | | What we did
Fit in 300 × 200 × 300 mm at the start | Arm folds to STOW on a low deck (103 mm); robot 293.7 × 196 × 292.9 mm
Grab an object centred at 450 mm, bot on the ground | Arm on the deck reaches ~640 mm; REACH_450 pose puts a cube centre at 449.6
| | mm
Ground clearance ≥ 50 mm | Ø140 wheels, motors on the axle line → lowest point 57 mm

Wheels always touch the ground; ramp 15°, bumps 40
mm

4WD, big wheels; checked in SolidWorks + physics simulation

Mechanical gripper only | The thenar-arms jaw gripper (no glue, magnets, suction)
Wi-Fi/BT, name TeamName_TF, authentication | ESP32 Wi-Fi AP, every command signed (HMAC-SHA256), replays rejected

Disconnect → motors stop, arm stops, gripper keeps
holding

Firmware HOLD state — tested in simulation with a Wi-Fi drop

On-board battery ≤ 24 V, secured, kill switch | 3S LiPo in a screwed cage, 15 A fuse, 30 A kill switch on the deck
No autonomous motion | Pure teleoperation: leader arm + joystick → robot

## Tasks and points (where the points are)

Task | Pts | Task | Pts | Task | Pts
Pickup (50 mm cube) | 10 | Stacker (3 cyl + cone) | 90 | Buzzed (wire loop) | 150
Ascent (15° ramp) | 30 | Longshot (throw cube) | ≤100 | Diagonals (250 mm track) | 20
Bridge (400 mm wide) | 10 | Robonardo (draw TF) | 130 | Escape room (4 shapes) | ≤100
Descent + speed breakers | 60 | Downy (cube at 400 mm) | 30 | Slalom ridge | 40
Touchdown (80 mm square) | 10 | Hanoi'd (tower of Hanoi) | 80 | The End (stop in zone) | 10

Our SolidWorks model of the 3 × 3 m arena (layout from the rulebook images, ±10 %)

Penalties to avoid: dropping the cube between pickup and touchdown (−15 each), wheels leaving the track (−10), touching the buzz wire (−20 each), letters outside the outline (−30). Practise Buzzed and Robonardo — 280 points need a steady arm, not speed.

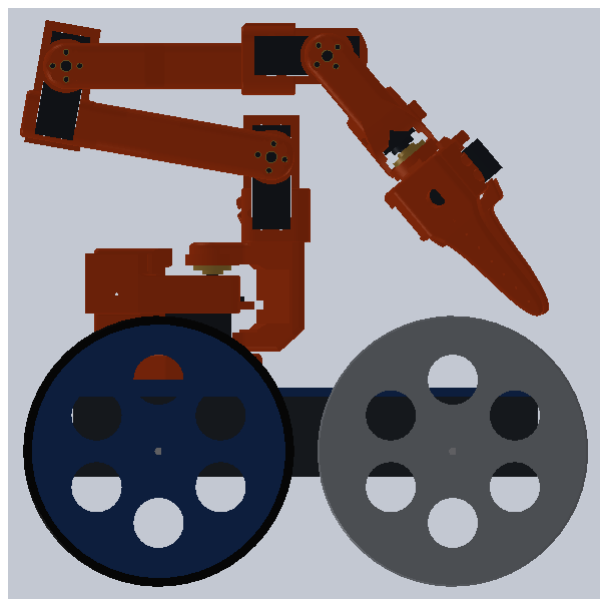
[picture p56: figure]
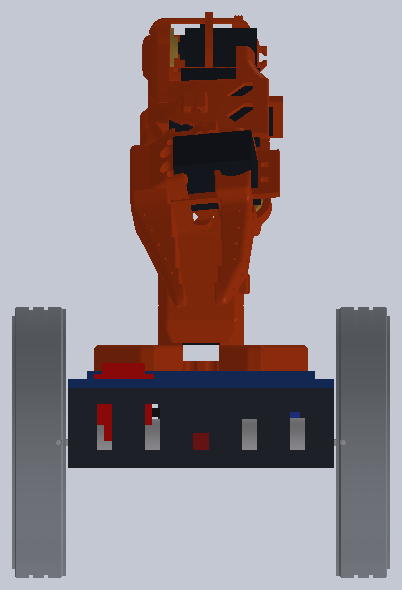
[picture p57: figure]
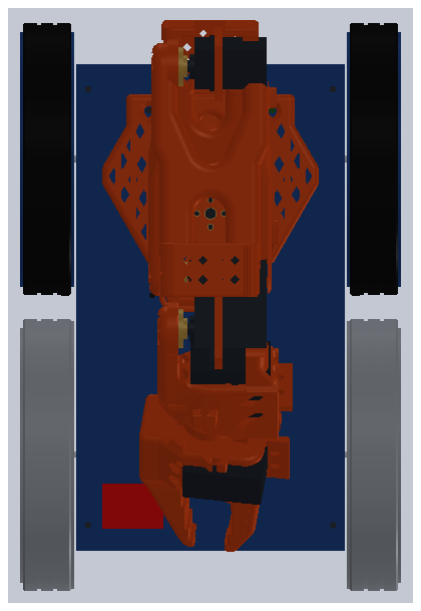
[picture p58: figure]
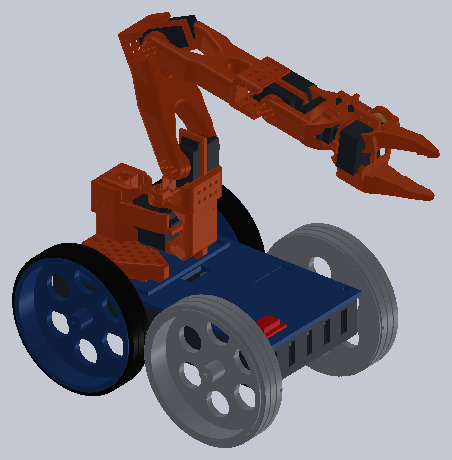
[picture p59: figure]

Everything here is generated from the project files (CAD + simulation). Nothing has been built or powered yet. | 3 / 12

# The robot at a glance

A printed 4WD chassis with the thenar-arms MG996R follower arm bolted on top (arm unchanged). The operator uses the thenar-arms encoder leader arm plus a thumb joystick.

Side (STOW) | Front (STOW)
Item | Value | Item | Value
Length × width × height (start) | 293.7 × 196 × 292.9 mm | Wheel diameter / width | 140 / 28 mm
Wheelbase / track | 152 / 168 mm | Ground clearance | 57 mm
Chassis tub | 240 × 138 mm, printed PETG | Deck top | 103 mm
Mass (CAD) | 2.39 kg | Centre of gravity height | 118 mm (STOW)
Battery | 3S LiPo 2200 mAh | Run time per pack | ~34 min (run is 7 min)

## How it is laid out

- Tub (floor 57 mm off the ground): 4 motors screwed to the side walls, battery in a cage on the left, 6 V buck + PCA9685 + 2 motor drivers on the right, 5 V buck at the back. ESP32 hangs under the deck.
- Deck (top at 103 mm): the arm base sits in a 4 mm fence and is bolted with 4 × M3 through its own vent slots. Kill switch at the front right.
- Why the deck is so low: the arm cannot fold lower than ~190 mm without hitting itself (we searched every pose with collision checking). On a normal 135 mm deck the robot would be 325 mm tall — too tall for the start box.
Top view | HOME pose (carrying pose)

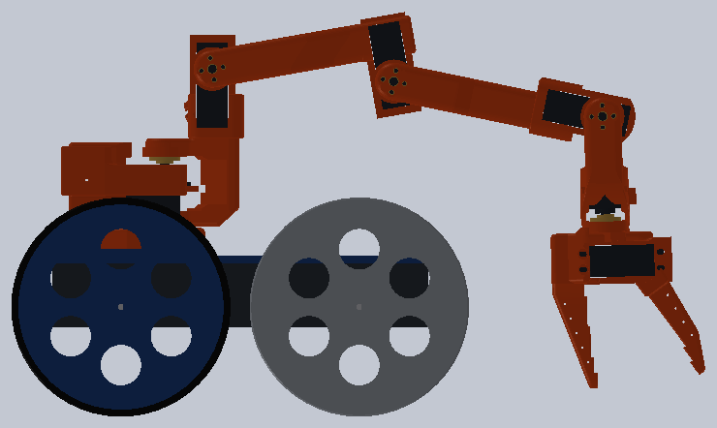
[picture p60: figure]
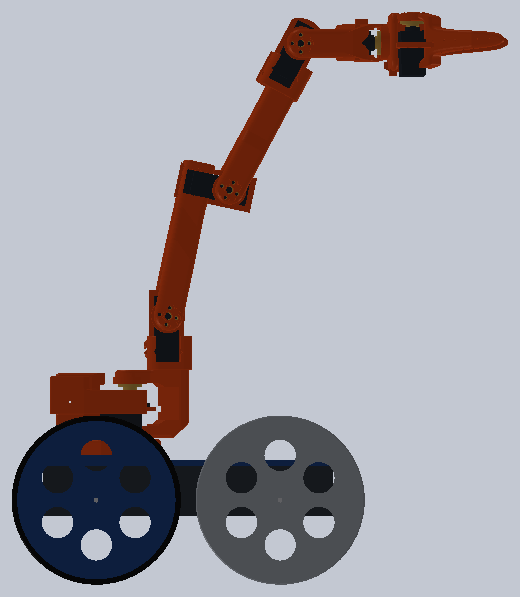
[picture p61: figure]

Everything here is generated from the project files (CAD + simulation). Nothing has been built or powered yet. | 4 / 12

# The arm: poses, reach and gripper

REACH_450 — cube centre at 449.6 mm, jaws closing sideways

PICK_FLOOR — 50 mm cube on the floor

## Arm poses (joint angles in degrees: pan, lift, elbow, wrist flex, wrist roll, gripper)

Pose | Joints | Use
STOW | 0, -80, 80, 50, 85, 0 | start box; fold here before the run
HOME | 0, -25, 35, 0, 0, 20 | carrying the cube over obstacles (most stable)
REACH_450 | -3.4, 12, -73.8, 61.3, -85, 35 | objects up to 450 mm (rule), Downy pole top
PICK_FLOOR | 0, 80, -68.3, 76.7, 3.4, 35 | cubes on the floor, 254 mm ahead of centre

## Gripper opening (measured on the real jaw meshes)

Gripper angle | 0° | 10° | 20° | 30° | 35° | 40° | 50° | 60°
Opening (mm) | 20 | 31 | 42 | 53 | 60 | 64 | 72 | 79
- 50 mm cube: grips around 28°. 60 mm cube / Ø60 cylinder: ~38°. Max ~79 mm.
- The jaws do not fully close (≈20 mm gap at 0°). Add 4 mm TPU finger pads so it can hold the Robonardo marker and grip thermocol better (the cube slid ~7 mm along bare fingers in the simulation).
- The URDF "tool point" is on the fixed finger; a held 50 mm object is centred 26.5 mm to the side. All heights here use the true object centre.

Driving rule: carry objects in HOME over the ramp, bridge and speed breakers. Stretched-out poses still pass the stability check, but HOME has the most margin (33 mm on the 15° descent).

Everything here is generated from the project files (CAD + simulation). Nothing has been built or powered yet. | 5 / 12

# Drive: motors, wheels and turning

Motor to buy

Name in shops | 25GA-370 12 V 60 RPM (same as JGA25-370 103:1)
How many | 4 (+1 spare)
Where | Robu.in ₹389 (in stock when checked); The Engineer Store ₹462
Check | 12 V · 60 RPM · 4 mm D-shaft · metal gears · no encoder
Do NOT buy | 100 RPM version — too weak for the ramp

Drive numbers

Ramp force (15°) | 9.16 N
Needed per motor | 1.63 kg·cm (4 driving)
Worst case | 3.27 kg·cm (2 driving, on a bump)
Motor rated / stall | 2.7 / 8.2 kg·cm
Speed | 0.34 m/s loaded, 0.44 free

Motor check when it arrives (10 min): put a printed wheel on one motor, tie a string to the tyre, hang a full 1 L water bottle, run at 12 V. It must lift it. Shops list different strengths for the same name — the simulation needs ≥ 6 kg·cm (5 gets stuck on the speed breakers). If it lifts it, buy the other three.

## How it steers — no steering servo, no steering shaft

Skid steering, like a tank or a JCB. One Cytron MDD10A drives both left wheels (channel 1) and both right wheels (channel 2). The ESP32 mixes the joystick: left = throttle − turn, right = throttle + turn. Different speeds on the two sides turn the robot; opposite directions spin it on the spot. Each wheel is fixed straight on its motor shaft.

front

Straight
both sides forward

front

Curve right
left fast, right slow

front

Spin right
left fwd, right back

front

Spin left
left back, right fwd

## Turning — why the front tyres are hard plastic

The robot is almost square (wheelbase 152 ≈ track 168), so every turn drags the tyres sideways. With rubbery TPU on all four wheels it could hardly turn. We tested options in the physics simulation:

Variant | Spin 35% | Spin 65% | Spin 100% | Arc turn | Top speed | Ramp
All TPU tyres (first design) | 0.2°/s | 31.6°/s | 83.6°/s | 2.8°/s | 0.53 m/s | yes
Stronger, slower motor, all TPU | 7.5°/s | 32.1°/s | 64.4°/s | 5.3°/s | 0.32 m/s | yes
Strongest motor, all TPU | 8.2°/s | 26.5°/s | 52.8°/s | 6.3°/s | 0.24 m/s | yes
PETG front + TPU rear (chosen) | 20.0°/s | 77.0°/s | 136.2°/s | 14.3°/s | 0.53 m/s | yes
Study done with a 77 rpm motor. The 60 RPM motor you buy was then re-checked in the full simulation: it spins 145° to within 0.2° and passes the whole course, a bit slower (~0.34 m/s).
- Front wheels: one-piece hard PETG. Rear wheels: PETG hub + TPU 95A tyre. Hard rear tyres were also tried: they get stuck on the speed breakers.
- Firmware gives turning its own power (50/75/100 %) with a 35 % minimum so a small stick push still turns.
- Drive like a car (curves while moving) where you can; spin on the spot for small corrections. In the 250 mm Diagonals corridor the robot (196 mm wide) cannot spin around — plan arcs.

Everything here is generated from the project files (CAD + simulation). Nothing has been built or powered yet. | 6 / 12

# Shopping list (1/2) — rover module

Everything for the driving base. Specs matter more than brand — check against the "Spec" column.

## Drive

Qty | Part | Spec / notes | Where to buy
4 (+1) | 25GA-370 12 V 60 RPM gear motor | 4 mm D-shaft, metal gears, no encoder. Do the 1 L bottle test. | Robu.in (₹389), The Engineer Store
1 | Cytron MDD10A dual motor driver | 10 A per channel, PWM + DIR, 84.5 × 62 mm. Already bought; sits on the deck top. | bought locally
4 | M3 × 5 grub screw (cup point) | Wheel hub onto the motor shaft flat | Local hardware / Robu
8 | M3 × 6 socket screw | Motor face to chassis wall (2 per motor) | Local hardware
2 m | 22 AWG silicone wire (red/black) | Motor leads | Robu / Amazon.in

## Power and safety

Qty | Part | Spec / notes | Where to buy
1 (+1) | 3S LiPo 2200 mAh 30C, XT60 | Max 106 × 34 × 26 mm to fit the cage | Robu / Amazon.in / hobby shop
1 | LiPo balance charger + LiPo-safe bag | Charge only in the bag, never unattended | Robu / Amazon.in
1 | KCD4 30 A DPST rocker (red) | The kill switch. Panel cut-out 22.2 × 30.2 mm | Robu / Amazon.in
1 | Inline blade fuse holder + 15 A fuse | Right after the battery | Car accessories shop
1 | XT60 male/female pair | Battery connector | Robu
1 | 6 V DC-DC buck, ≥ 10 A | XL4016 / "300 W 20 A" type, adjustable. Feeds the 6 servos | Robu / Amazon.in
1 | MP1584 mini buck | Set to 5.0 V for the ESP32 | Robu
1 m | 16 AWG silicone wire | Battery → fuse → switch → drivers | Robu

## Brains

Qty | Part | Spec / notes | Where to buy
1 | ESP32-DevKitC (WROOM-32E, 38 pin) | The robot controller (Wi-Fi AP + motors + servos) | Robu / Amazon.in
1 | PCA9685 16-ch PWM board | Drives the 6 arm servos over I²C | Robu
1 + 1 | Resistors 100 kΩ + 27 kΩ | Battery voltage sense | Any
1 lot | Jumper wires, servo extensions, heat-shrink, zip ties | | Any

## Rover prints — 5 ready P1S plates in cad/print, no supports (~29 h total)

Qty | Part | Spec / notes | Where to buy
1 | Plate 1: tub + battery cage + 2 bars | PETG, 4 walls, 30 % gyroid (~7 h, ~260 g) | P1S
1 | Plate 2: deck plate | PETG, 250 mm long — fits the P1S bed (~3 h, ~130 g) | P1S
2 | Plates 3 + 4: front wheel + rear hub | PETG, ~5.4 h each; front wheels are one piece (hard tread). Print plate 3 first (motor test) | P1S
1 | Plate 5: 2 rear tyres | TPU 95A, 3 walls, 20 % (~7.7 h, ~90 g) | P1S

Everything here is generated from the project files (CAD + simulation). Nothing has been built or powered yet. | 7 / 12

# Shopping list (2/2) — arm, controller, hardware

## Arm — the thenar-arms MG996R follower (unchanged; full list in thenar-arms R3-PRINT.md)

Qty | Part | Spec / notes | Where to buy
6 | MG996R servo (180°) | Pan, lift, elbow, wrist flex, wrist roll, gripper | Robu / Amazon.in
6 | Metal servo horn 25T, Ø20 mm disc | 4 × M3 on 14 mm circle — must match your servo spline | Robu
24 / 24 / 48 | M3 × 12 screws / nuts / washers | Servo tabs | Local hardware
24 | M3 × 8 screws | Horns to links | Local hardware
7 | Arm prints (R3) | Base, shoulder, upper arm, forearm, wrist, gripper body, jaw — PETG | Print
2 | TPU finger pads, 4 mm | Recommended (marker + grip) | Print
4 | M3 × 20 + washer + nyloc | Arm base to deck, through its vent slots | Local hardware

## Controller — added to the thenar-arms encoder leader

Qty | Part | Spec / notes | Where to buy
1 | Leader arm (thenar-arms L1) | 6 × AS5600, TCA9548A, ESP32, bearings — its own BOM | Already designed
1 | 2-axis thumb joystick module | 3.3 V; VRx → GPIO34, VRy → GPIO35 | Robu
1 | Toggle switch (ENABLE) | GPIO32 to GND | Robu
1 | Push button (SPEED) | GPIO33 to GND | Robu
1 | USB power bank + cable | Powers the leader ESP32 | Any

## Chassis hardware

Qty | Part | Spec / notes | Where to buy
4 | M3 heat-set insert (Ø4.0 bore) | Tub corner columns | Robu / Amazon.in
4 | M3 × 10 socket screw | Deck to tub | Local hardware
2 | M3 × 8 + nyloc | Battery cage to floor | Local hardware
4 | M3 × 8 self-tapping | Battery bars | Local hardware
20 | M2.5 × 6 self-tapping | Boards to the floor standoffs | Local hardware
2 | M2.5 × 10 brass standoff (F-F) | ESP32 under the deck | Robu

## Filament and tools

Qty | Part | Spec / notes | Where to buy
~0.81 kg | PETG | Rover plates 1–4 (+ the arm parts if not printed yet)
~87 g | TPU 95A | Rear tyres (+ finger pads)
— | Soldering iron, heat-set insert tip, multimeter, hex keys, crimper | Multimeter is a must for setting the bucks

Not needed: camera, Raspberry Pi, encoders, IMU. The ESP32 is the right brain here: boots in under a second, survives the kill switch (no SD card), and the safety firmware is already written and tested. Add an ESP32-CAM later only if you want a camera view.

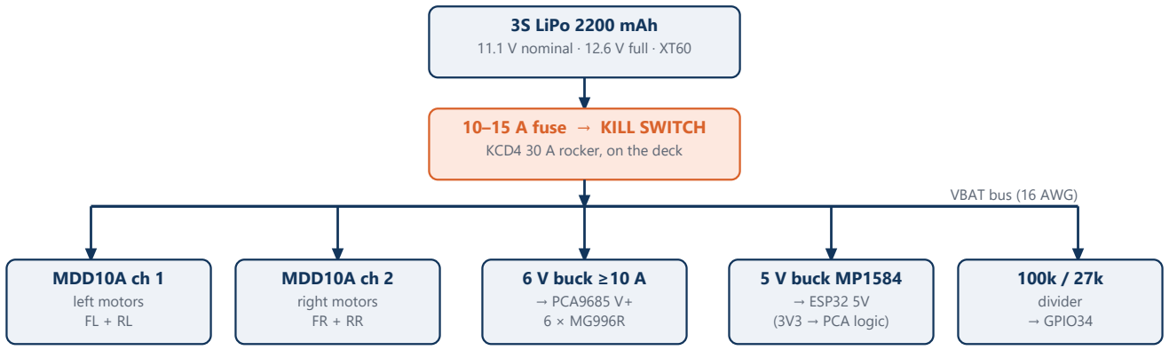
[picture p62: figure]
3S LiPo 2200 mAh; 11.1 V nominal · 12.6 V full · XT60; 10–15 A fuse → KILL SWITCH; KCD4 30 A rocker, on the deck; VBAT bus (16 AWG); MDD10A ch 1; left motors; MDD10A ch 2; right motors; 6 V buck ≥10 A; → PCA9685 V+; 5 V buck MP1584; → ESP32 5V (3V3 → PCA logic); divider; → GPIO34

Everything here is generated from the project files (CAD + simulation). Nothing has been built or powered yet. | 8 / 12

# Wiring

## Power

All grounds common. Every voltage on the robot ≤ 12.6 V (rule: ≤ 24 V DC). Kill switch is before everything → it shuts the whole robot down (rule).

## Robot ESP32 pins

ESP32 pin | Goes to | ESP32 pin | Goes to
GPIO21 / 22 | PCA9685 SDA / SCL | GPIO16 / 17 | MDD10A PWM2 / DIR2 (right motors)
GPIO13 | PCA9685 OE (servo output enable) | GND | MDD10A header GND (pin 1)
GPIO25 / 26 | MDD10A PWM1 / DIR1 (left motors) | GPIO34 | battery divider (100k / 27k)
GPIO2 | on-board LED (solid = ACTIVE)
5V / GND | 5 V buck output | 3V3 | PCA9685 VCC (logic only)
PCA9685 ch | Servo
0 | J1 shoulder pan
1 | J2 shoulder lift
2 | J3 elbow
3 | J4 wrist flex
4 | J5 wrist roll
5 | J6 gripper

Controller (leader
ESP32)
GPIO34 / 35 | joystick X (turn) / Y (throttle)
GPIO32 | ENABLE toggle → GND
GPIO33 | SPEED button → GND
3V3 / GND | joystick power (not 5 V)
21 / 22 | leader encoders (unchanged)

Before connecting: set the 6 V buck to 6.0 V and the 5 V buck to 5.0 V with a multimeter, no load. Never power servos from the ESP32 or USB. MDD10A: M1A/M1B = both left motors in parallel, M2A/M2B = both right; 10 kΩ from PWM1 and PWM2 to GND. Whole side backwards: swap that side's A/B wires. One wheel fighting its partner: swap that motor's two wires.

Everything here is generated from the project files (CAD + simulation). Nothing has been built or powered yet. | 9 / 12

# Firmware, radio link and safety

Two ESP32 programs share one library (ThenarLink). The safety logic is unit-tested on a PC (39/39 checks) and was run inside the physics simulation.

no packet 250 ms / ENABLE off / bad data

The kill switch cuts power in every state.

## What judges will check — and how we meet it

Rule | How
Name TeamName_TF | Robot makes a WPA2 Wi-Fi network called <TeamName>_TF (spaces removed, max 20 chars), 1 device max
Only our controller | Every packet signed with a 32-byte secret key (HMAC-SHA256); new session id per pairing; old/copied packets rejected
Disconnect | 250 ms without a valid packet → HOLD: wheels stop at once, arm freezes, gripper keeps holding
Stays disabled | Moves again only on a NEW valid command; arm catches up slowly (45°/s) for 1.5 s
Kill switch | Hardware, in series with the battery — cuts everything

## Driving controls

ENABLE switch on = robot may move. SPEED button cycles precision 35 % / normal 65 % / fast 100 % for driving (turning 50 / 75 / 100 %). Power-up: the arm only engages when the leader arm is folded to STOW (within 6°), so it can never jump.

## Set up and flash

Step | Command / action
1. Make your secret key | python firmware/tools/new_key.py "Your Team Name"
2. Test the logic on a PC | powershell -File firmware/tests/run_tests.ps1 (39 checks)
3. Compile both sketches | powershell -File firmware/tools/compile_firmware.ps1
4. Flash | thenar_walker_bot → robot ESP32; thenar_walker_controller → leader ESP32
5. Leader calibration | Hold leader at HOME, send ZERO in the serial monitor; SIGN <axis> -1 for reversed joints; JOYZERO
6. Servo calibration | Measure each servo zero/direction with horns off → calibration.h → FOLLOWER_CALIBRATED = true

Until servo calibration is done, the robot drives but the arm stays limp — on purpose. Never share or commit team_config.h.

Everything here is generated from the project files (CAD + simulation). Nothing has been built or powered yet. | 10 / 12

# Build guide

## 0 · Before buying everything

☐ Buy one motor first and do the 1 L bottle test (page 5).

☐ Measure motor and boards against the CAD; change cad/tools/design.py if different.

## 1 · Print

☐ The 5 plates in cad/print (PETG plates 1–4, TPU plate 5) — plate 3 first. No supports. Plus the 7 arm parts.

## 2 · Tub

☐ Melt 4 M3 inserts into the corner columns.

☐ Screw the battery cage to the floor.

☐ Drop motors into the U-slots, gearbox face on the wall, 2 × M3 × 6 each (solder leads first).

☐ Screw the 6 V buck, PCA9685 and the 5 V buck to the floor standoffs (2 pads stay spare).

☐ Set bucks to 6.0 V / 5.0 V. Wire per page 8, kill switch OFF.

## 3 · Wheels

☐ TPU tyres onto the 2 rear hubs; the 2 front wheels are one piece. Push onto the D-shaft ~1 mm off the wall, grub screw on the flat.

## 4 · Deck and arm

☐ Screw 2 brass standoffs under the deck and zip-tie the ESP32 to them, snap in the kill switch, route servo leads through the slot. MDD10A onto the 4 deck-top bosses, terminals forward, wires down the front slot.

☐ Battery into the cage, screw on the bars. Deck onto the tub with 4 × M3 × 10.

☐ Arm base into the fence, 4 × M3 × 20 through the base vent slots, nylocs under the deck. Servos J1..J6 → PCA ch 0..5.

## 5 · Firmware

☐ Key, compile, flash, calibrate — page 9.

## 6 · First power-up (wheels off the ground)

☐ Robot and leader in STOW, ENABLE off, kill switch on.

☐ ENABLE on → LED solid. Check every wheel direction.

☐ Failsafe test: while driving and holding a cube, switch the controller off → wheels stop, arm freezes, cube stays in the gripper. Repeat this at inspection.

## 7 · Before every run

☐ Battery ≥ 11.4 V, team key is not the example, robot folded in STOW and inside the 300 × 200 × 300 box.

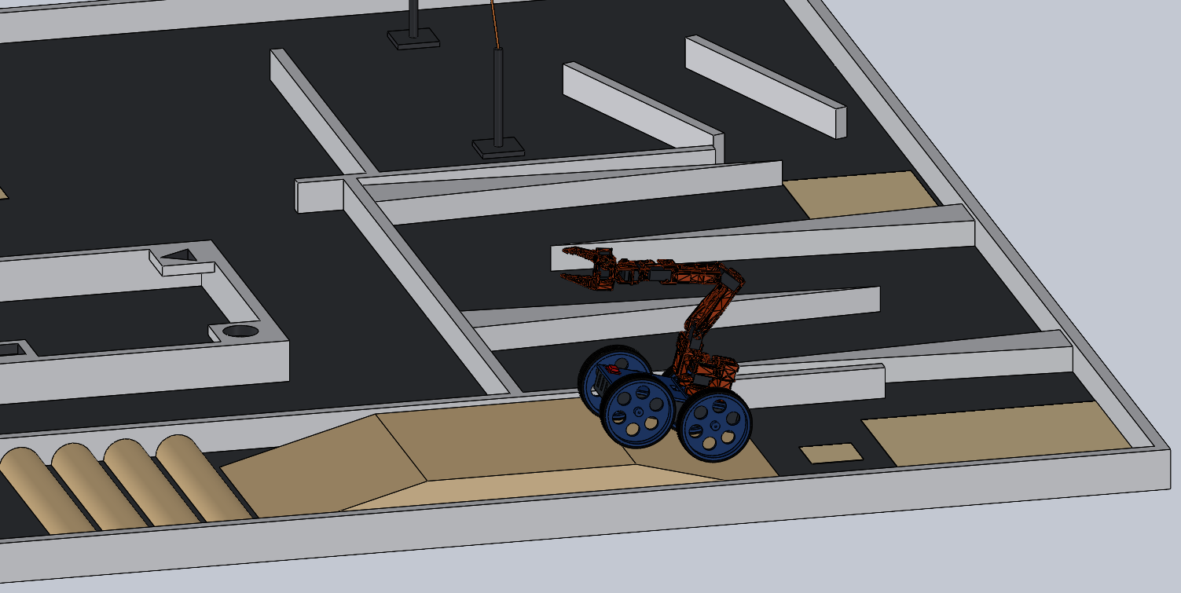
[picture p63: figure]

Everything here is generated from the project files (CAD + simulation). Nothing has been built or powered yet. | 11 / 12

# Verified in SolidWorks

Native SolidWorks 2026 parts and assemblies, generated by scripts. Checks use exact geometry (body extreme points, interference detection). The arm matches the URDF kinematics to 0.04 mm.

Result | Check | Measured
PASS | Start box 300 x 200 x 300 (STOW) | 293.7 x 196.0 x 292.9 mm
PASS | Ground clearance >= 50 mm (STOW) | 57.0 mm at chassis tub
PASS | Ground clearance >= 50 mm (HOME) | 57.0 mm at chassis tub
PASS | Ground clearance >= 50 mm (REACH_450) | 57.0 mm at chassis tub
PASS | Grasp object centred at 450 mm (REACH_450) | 50 mm object centre z = 449.6 mm, 140 mm ahead of the chassis
PASS | Floor pick: 50 mm cube on the ground ahead of the wheels | grasp centre [254.4, -0.2, 25.1] (cube centre z = 25)
PASS | No interference (STOW) | clear
PASS | No interference (HOME) | clear
PASS | No interference (REACH_450) | clear
PASS | No interference (PICK_FLOOR) | clear
PASS | Static stability (STOW, flat + 15 deg ramp) | worst margin 36.3 mm
PASS | Static stability (HOME, flat + 15 deg ramp) | worst margin 32.9 mm
PASS | Static stability (REACH_450, flat + 15 deg ramp) | worst margin 24.5 mm
PASS | Static stability (PICK_FLOOR, flat + 15 deg ramp) | worst margin 20.5 mm

Robot placed on the arena's real ramp, bridge and speed breakers at 9 positions: only the tyres touch — the chassis, motors and arm never hit an obstacle.

On the 15° ramp
Speed breaker under the belly

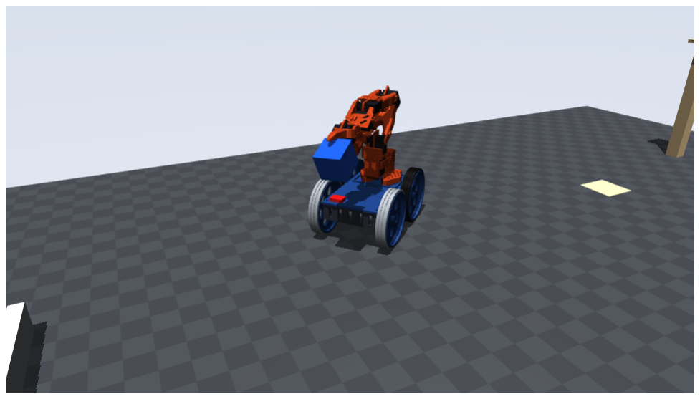
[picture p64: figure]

Everything here is generated from the project files (CAD + simulation). Nothing has been built or powered yet. | 12 / 12

# Simulated end-to-end run

MuJoCo physics (real masses, motor torque curve, servo limits, tyre friction) with our actual firmware logic in the loop. A scripted "operator" drives the leader arm and joystick like a person would.

Mission | What | Result | Time

A Pick 50 mm cube → 15° ramp → bridge → down → 4 speed breakers → place in 80
| mm square | PASS 7/7 | 28 s
B | Same + 1.5 s Wi-Fi drop on the bridge + 75 fake/replayed packets | PASS 12/12 | 29 s
C | Downy: 60 mm cube off the 400 mm pole, turn, place in its square | PASS 5/5 | 55 s

Wi-Fi drop: speed 0 mm/s at end, rolled 11 mm after HOLD; max joint drift 0.21 deg; attacks: 75 attack packets, 0 accepted.

Picking the cube | Over the speed breakers, cube held | Cube taken off the 400 mm pole

## What the simulation does NOT prove

Tyre and gripper friction are estimates; real thermocol dents (squeeze gently); the scripted operator never shakes. Videos: sim/out/mission_A.mp4, mission_B.mp4, mission_C.mp4.

## Team checklist

☐ Order 1 motor → bottle test → order the rest + all electronics (pages 6–7)

☐ Print the 5 rover plates (cad/print, plate 3 first) and the arm

☐ Build and wire (pages 8, 10); set both bucks before connecting

☐ Flash, calibrate the leader and the servos (page 9)

☐ Test on the real floor: turning, the ramp, a 40 mm bump, the failsafe

☐ Practise: Buzzed (150) and Robonardo (130) are a third of all points

☐ Register the team; the SSID must be YourTeamName_TF

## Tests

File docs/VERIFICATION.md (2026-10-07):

# Verification report — Thenar Walker

Generated by `cad/tools/make_report.py` from `cad/evidence/*.json` (SolidWorks 2026 SP4.1 API runs) and `analysis/*.json`. Re-run the tools to refresh; do not edit by hand.

## RoboReach rule checks (SolidWorks, exact B-rep)

| Result | Check | Measured |
|---|---|---|
| PASS | Start box 300 x 200 x 300 (STOW) | 293.7 x 196.0 x 292.9 mm |
| PASS | Ground clearance >= 50 mm (STOW) | 57.0 mm at RR-01_Chassis_Tub-1 |
| PASS | Ground clearance >= 50 mm (HOME) | 57.0 mm at RR-01_Chassis_Tub-1 |
| PASS | Ground clearance >= 50 mm (REACH_450) | 57.0 mm at RR-01_Chassis_Tub-1 |
| PASS | Grasp object centred at 450 mm (REACH_450) | 50 mm object centre z = 449.6 mm, 140 mm ahead of the chassis |
| PASS | Floor pick: 50 mm cube on the ground ahead of the wheels | grasp centre [254.4, -0.2, 25.1] (cube centre z = 25) |
| PASS | No interference (STOW) | clear (+6 intended servo-spline/horn overlaps from the arm CAD) |
| PASS | No interference (HOME) | clear (+6 intended servo-spline/horn overlaps from the arm CAD) |
| PASS | No interference (REACH_450) | clear (+6 intended servo-spline/horn overlaps from the arm CAD) |
| PASS | No interference (PICK_FLOOR) | clear (+6 intended servo-spline/horn overlaps from the arm CAD) |
| PASS | Static stability (STOW, flat + 15 deg ramp) | worst margin 36.6 mm: {'front': 83.7, 'rear': 68.3, 'left': 80.1, 'right': 87.9, 'climb_15deg_rear_axle': 36.6, 'descend_15deg_front_axle': 52.0, 'traverse_15deg_side': 48.4} |
| PASS | Static stability (HOME, flat + 15 deg ramp) | worst margin 32.3 mm: {'front': 67.6, 'rear': 84.4, 'left': 80.4, 'right': 87.6, 'climb_15deg_rear_axle': 49.2, 'descend_15deg_front_axle': 32.3, 'traverse_15deg_side': 45.2} |
| PASS | Static stability (REACH_450, flat + 15 deg ramp) | worst margin 23.9 mm: {'front': 63.4, 'rear': 88.6, 'left': 78.8, 'right': 89.2, 'climb_15deg_rear_axle': 49.1, 'descend_15deg_front_axle': 23.9, 'traverse_15deg_side': 39.3} |
| PASS | Static stability (PICK_FLOOR, flat + 15 deg ramp) | worst margin 19.9 mm: {'front': 48.1, 'rear': 103.9, 'left': 80.4, 'right': 87.6, 'climb_15deg_rear_axle': 75.7, 'descend_15deg_front_axle': 19.9, 'traverse_15deg_side': 52.2} |

How each number is measured:

* **Start box** — exact extreme points of every solid body (`IBody2.GetExtremePoint`) in the STOW configuration.
* **Ground clearance** — lowest extreme point of every component except hubs/tyres.
* **Grasp centre** — URDF forward kinematics of the `gripper_frame_link`; the SolidWorks arm matches the URDF to 0.04 mm in every pose (table below).
* **Interference** — SolidWorks Interference Detection through all sub-assembly levels. The six servo-spline/horn overlaps (9.0 mm³ each) are how the thenar-arms CAD models the horn press-fit and are listed, not failed.
* **Stability** — centre of gravity from SolidWorks volumes/centroids × datasheet masses (printed parts at 1.27 g/cm³ × 0.55 fill), projected onto the wheel-contact rectangle, flat and on a 15° ramp.

### Per configuration

| Config | Joint angles (deg) | Size L×W×H (mm) | Lowest non-wheel z | Mass | COG (mm) | Grasp centre (mm) |
|---|---|---|---|---|---|---|
| STOW | [0, -80, 80, 50, 85, 0] | 293.7 × 196.0 × 292.9 | 57.0 | 2398 g | [-7.7, 3.9, 118.3] | [120.7, 18.2, 148.0] |
| HOME | [0, -25, 35, 0, 0, 20] | 417.1 × 196.0 × 358.1 | 57.0 | 2398 g | [8.4, 3.6, 131.4] | [261.7, -1.3, 306.8] |
| REACH_450 | [-3.4, 12.0, -73.8, 61.3, -85.0, 35] | 410.6 × 196.0 × 473.5 | 57.0 | 2398 g | [12.6, 5.2, 147.4] | [260.0, -0.5, 449.6] |
| PICK_FLOOR | [0, 80, -68.3, 76.7, 3.4, 35] | 442.6 × 196.0 × 258.3 | 17.95 | 2398 g | [27.9, 3.6, 105.2] | [254.4, -0.2, 25.1] |

## Arm: SolidWorks vs URDF forward kinematics

| Pose | max bounding-box difference (mm) |
|---|---|
| ZERO | 0.04 |
| HOME | 0.04 |
| STOW | 0.04 |
| REACH_450 | 0.05 |
| PICK_FLOOR | 0.05 |

## Obstacles: robot on the arena ramp, bridge and speed breakers (SolidWorks)

Robot pose solved so both axles' tyres rest tangent on the real profile (`cad/tools/terrain.py`), then SolidWorks interference between every robot component and the arena board.

| Case | Pitch (deg) | Chassis/motor/arm hits | Tyre contact overlaps | Result |
|---|---|---|---|---|
| ramp_foot | 6.52 | 0 | 0 (max 0 mm³) | PASS |
| on_ramp | 15.02 | 0 | 6 (max 0.0 mm³) | PASS |
| ramp_crest | 3.12 | 0 | 6 (max 0.0 mm³) | PASS |
| bridge | 0.0 | 0 | 12 (max 0.0 mm³) | PASS |
| bridge_exit | -11.16 | 0 | 6 (max 0.0 mm³) | PASS |
| down_ramp_foot | 5.88 | 0 | 0 (max 0 mm³) | PASS |
| front_on_breaker_1 | 4.88 | 0 | 0 (max 0 mm³) | PASS |
| breaker_under_belly | 0.02 | 0 | 6 (max 0.0 mm³) | PASS |
| rear_on_breaker_4 | -15.24 | 0 | 6 (max 0.0 mm³) | PASS |

## Drive and power sizing (`analysis/drive_sizing.py`)

| Quantity | Value |
|---|---|
| mass_for_sizing_kg | 2.61 |
| ramp_force_N | 9.16 |
| wheel_torque_total_Nm | 0.641 |
| per_motor_kgcm_4wd | 1.63 |
| per_motor_kgcm_2_driving | 3.27 |
| rated_kgcm | 2.7 |
| stall_kgcm | 8.2 |
| margin_4wd_vs_rated | 1.65 |
| margin_2wd_vs_stall | 2.51 |
| speed_rated_m_s | 0.34 |
| speed_free_m_s | 0.44 |
| battery_current_avg_A | 3.11 |
| battery_current_peak_A | 10.61 |
| runtime_avg_min_2200mAh_80pct | 34.0 |
| servo_6V_peak_A | 8.4 |
| fuse_A | 15 |

## Gripper opening (`analysis/gripper_gap.py`, URDF meshes)

| Gripper joint (deg) | Inner gap 15 mm behind the tips (mm) |
|---|---|
| 0 | 19.7 |
| 5 | 25.4 |
| 10 | 31.1 |
| 15 | 36.8 |
| 20 | 42.5 |
| 25 | 47.9 |
| 30 | 53.2 |
| 35 | 60.1 |
| 40 | 63.8 |
| 45 | 69.2 |
| 50 | 72.2 |
| 55 | 74.1 |
| 60 | 79.0 |
| 65 | 77.3 |
| 70 | 70.4 |

## Not verified (needs the real robot)

* Real part dimensions (motor shaft length, board sizes, servo spline) — the CAD uses nominal envelopes.
* Print strength, tyre grip on the actual arena surface, dynamic tipping under hard braking.
* Servo calibration and powered arm motion (thenar-arms R3 is itself not yet physically validated).
* Radio range/latency in a crowded venue; firmware is compiled and unit-tested on the host, not run on hardware.
* Arena positions are reconstructed from the rulebook renders (the rulebook allows ~10 % differences).

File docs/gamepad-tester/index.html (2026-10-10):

# Thenar Pad Check

Press any button on the controller. Everything you touch lights up here and moves the Thenar Walker below, with the same layout the robot uses.

no controller Test vibration Reset rover

Real robot Drive the real robot not linked Connect this PC to the robot's Wi-Fi ThenarWalker_TF first. Then the controller drives the robot exactly like the 3D model. Close this tab or lose Wi-Fi and the robot stops in 0.5 s.

## Controllerwaiting

## What it moves

## Thenar Walkerdrag to orbit · scroll to zoom

MID 65 % ARM ON

L

0 % R

0 %

waiting for a controller — press any button on it

## Raw signals— Hz

Sticks at rest should sit inside the shaded band (±0.12). Outside it = stick drift.

## Events

- Waiting for a controller. Press any button on it.

## Connect the controller

PC with the USB dongle

1. Plug the receiver in, switch the controller on.
2. Press any button here. The chip at the top turns green.

PC or phone over Bluetooth

1. Put the controller in pairing mode (see its manual — usually HOME + a mode button until the LED flashes fast).
2. Pair it in the system Bluetooth settings.
3. Open this page in Chrome or Edge and press any button.

No controller? Keyboard works too: WASD drive · arrows right stick · IKJL d-pad · Y/H wrist · Q/E gripper · Z/C speed · B stop · X fine · hold Enter arm on · hold Backspace limp.

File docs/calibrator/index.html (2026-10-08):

# Thenar arm calibrator

not connected PCA9685 ? Connect ESP32 ALL SERVOS OFF

This browser has no Web Serial. Open this page in Chrome or Edge on a computer (not a phone).

Before you start (read once)

1. The ESP32-S3 runs firmware/arm_calibration (already flashed). PCA9685 on SDA 8, SCL 9, OE 10.
2. Servo power: 6 V buck → PCA9685 V+ / GND, never from USB. Put a 470–1000 µF capacitor across V+/GND if you have one.
3. Do one joint at a time. When you press Start this joint the servo jumps to its start pulse at full speed (a servo has no position sensor). Keep fingers and cables clear. ALL SERVOS OFF makes everything limp.
4. Order: gripper → wrist roll → wrist flex → base pan → elbow → shoulder (light joints first, the heavy shoulder last).
5. For each joint: jog to Reference A, press Set A; jog to Reference B, press Set B. The app works out zero, direction and µs per degree. Then jog to each safe end (stop 3–5° before anything touches) and press Set end twice. Test, then Mark joint done.
6. When all 6 are done: Save to robot (stored on the ESP32) and copy calibration.h into firmware/thenar_walker_bot/.
7. If the zero pulse lands outside about 1200–1800 µs, move the horn one spline tooth and redo the joint — otherwise one end of the range is too short.

### Joints

Slew speed300 µs/s

Shoulder won't move / jitters? Measure V+ at the PCA9685 while the shoulder moves: below 5.5 V = supply or wires too weak (use the 6 V ≥ 10 A buck, 18 AWG or thicker, add the capacitor). If it moves fine with the horn off but not on the arm, it's load or binding — not calibration.

## Pick a joint

not started

Start this joint start pulse µs Release this joint

pulse

−50−10 −2+2 +10+50

keyboard: ← → = ±10, Shift = ±50, Alt = ±2

Reference A · °

Set A here—

Reference B · °

Set B here— angle

Result:needs A and B

Set safe end here ends: — / — Clear ends

Test: Go to angle Go to 0°Sweep ends

Mark joint done Reset this joint

## All joints

Load from robot Save to robot Copy calibration.h

### Serial log

Send

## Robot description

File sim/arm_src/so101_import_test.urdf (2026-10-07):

<?xml version='1.0' encoding='utf-8'?>
<robot name="so101_mg996r_follower_r3">
  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
  <link name="base_link">
    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
  </link>
  <link name="shoulder_link">
    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
  </link>
  <link name="upper_arm_link">
    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
  </link>
  <link name="lower_arm_link">
    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
  </link>
  <link name="wrist_link">
    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
  </link>
  <link name="gripper_link">
    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
  </link>
  <link name="moving_jaw_so101_v1_link">
    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
  </link>
  <joint name="shoulder_pan" type="revolute">
    <parent link="base_link" />
    <child link="shoulder_link" />
    <origin xyz="0.0388353 -8.97657000000347e-09 0.0624" rpy="-3.14159265358305 0 -3.14159265358979" />
    <axis xyz="0 0 1" />
    <limit lower="-1.4835298641951802" upper="1.4835298641951802" effort="0" velocity="0.17453292519943295" />
  </joint>
  <joint name="shoulder_lift" type="revolute">
    <parent link="shoulder_link" />
    <child link="upper_arm_link" />
    <origin xyz="-0.0303992 -0.0182778 -0.0542" rpy="-1.5707963267949 -1.5707963267949 0" />
    <axis xyz="0 0 1" />
    <limit lower="-1.3962634015954636" upper="1.3962634015954636" effort="0" velocity="0.17453292519943295" />
  </joint>
  <joint name="elbow_flex" type="revolute">
    <parent link="upper_arm_link" />
    <child link="lower_arm_link" />
    <origin xyz="-0.11257 -0.028 3.5527136788005e-18" rpy="2.22044604925031e-16 0 1.5707963267949" />
    <axis xyz="0 0 1" />
    <limit lower="-1.3962634015954636" upper="1.3962634015954636" effort="0" velocity="0.17453292519943295" />
  </joint>
  <joint name="wrist_flex" type="revolute">
    <parent link="lower_arm_link" />
    <child link="wrist_link" />
    <origin xyz="-0.1349 0.00519999999999999 -1.06581410364015e-17" rpy="2.22044604925031e-16 0 -1.5707963267949" />
    <axis xyz="0 0 1" />
    <limit lower="-1.3962634015954636" upper="1.3962634015954636" effort="0" velocity="0.17453292519943295" />
  </joint>
  <joint name="wrist_roll" type="revolute">
    <parent link="wrist_link" />
    <child link="gripper_link" />
    <origin xyz="1.13686837721616e-16 -0.0691 0.0181" rpy="1.5707963267949 0.0486794999899367 3.14159265358979" />
    <axis xyz="0 0 1" />
    <limit lower="-1.4835298641951802" upper="1.4835298641951802" effort="0" velocity="0.17453292519943295" />
  </joint>
  <joint name="gripper" type="revolute">
    <parent link="gripper_link" />
    <child link="moving_jaw_so101_v1_link" />
    <origin xyz="0.0202 0.0188 -0.0234" rpy="1.5707963267949 0 0" />
    <axis xyz="0 0 1" />
    <limit lower="0.0" upper="1.2217304763960306" effort="0" velocity="0.17453292519943295" />
  </joint>
  <link name="gripper_frame_link" />
  <joint name="gripper_tool_fixed" type="fixed">
    <parent link="gripper_link" />
    <child link="gripper_frame_link" />
    <origin xyz="-0.0079 -0.000218121 -0.0981274" rpy="3.14159265358979 0 3.14159265358979" />
  </joint>
  <mujoco>
    <compiler meshdir="meshes" discardvisual="false" fusestatic="false" />
  </mujoco>
</robot>

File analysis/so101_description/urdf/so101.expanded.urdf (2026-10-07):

<?xml version="1.0" ?>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<robot name="so101_mg996r_follower_r3">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<link name="base_link">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</link><link name="shoulder_link">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</link><link name="upper_arm_link">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</link><link name="lower_arm_link">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</link><link name="wrist_link">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</link><link name="gripper_link">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</link><link name="moving_jaw_so101_v1_link">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</link><joint name="shoulder_pan" type="revolute"><parent link="base_link"/><child link="shoulder_link"/><origin rpy="-3.14159265358305 0 -3.14159265358979" xyz="0.0388353 -8.97657000000347e-09 0.0624"/><axis xyz="0 0 1"/><limit effort="0" lower="-1.4835298641951802" upper="1.4835298641951802" velocity="0.17453292519943295"/></joint><joint name="shoulder_lift" type="revolute"><parent link="shoulder_link"/><child link="upper_arm_link"/><origin rpy="-1.5707963267949 -1.5707963267949 0" xyz="-0.0303992 -0.0182778 -0.0542"/><axis xyz="0 0 1"/><limit effort="0" lower="-1.3962634015954636" upper="1.3962634015954636" velocity="0.17453292519943295"/></joint><joint name="elbow_flex" type="revolute"><parent link="upper_arm_link"/><child link="lower_arm_link"/><origin rpy="2.22044604925031e-16 0 1.5707963267949" xyz="-0.11257 -0.028 3.5527136788005e-18"/><axis xyz="0 0 1"/><limit effort="0" lower="-1.3962634015954636" upper="1.3962634015954636" velocity="0.17453292519943295"/></joint><joint name="wrist_flex" type="revolute"><parent link="lower_arm_link"/><child link="wrist_link"/><origin rpy="2.22044604925031e-16 0 -1.5707963267949" xyz="-0.1349 0.00519999999999999 -1.06581410364015e-17"/><axis xyz="0 0 1"/><limit effort="0" lower="-1.3962634015954636" upper="1.3962634015954636" velocity="0.17453292519943295"/></joint><joint name="wrist_roll" type="revolute"><parent link="wrist_link"/><child link="gripper_link"/><origin rpy="1.5707963267949 0.0486794999899367 3.14159265358979" xyz="1.13686837721616e-16 -0.0691 0.0181"/><axis xyz="0 0 1"/><limit effort="0" lower="-1.4835298641951802" upper="1.4835298641951802" velocity="0.17453292519943295"/></joint><joint name="gripper" type="revolute"><parent link="gripper_link"/><child link="moving_jaw_so101_v1_link"/><origin rpy="1.5707963267949 0 0" xyz="0.0202 0.0188 -0.0234"/><axis xyz="0 0 1"/><limit effort="0" lower="0.0" upper="1.2217304763960306" velocity="0.17453292519943295"/></joint><link name="gripper_frame_link"/><joint name="gripper_tool_fixed" type="fixed"><parent link="gripper_link"/><child link="gripper_frame_link"/><origin rpy="3.14159265358979 0 3.14159265358979" xyz="-0.0079 -0.000218121 -0.0981274"/></joint></robot>

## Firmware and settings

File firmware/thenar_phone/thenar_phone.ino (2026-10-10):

// Thenar Walker — phone control, low latency (ESP32-S3 + PCA9685 arm + Cytron MDD10A wheels).
// The robot is a Wi-Fi access point "<Team>_TF" (WPA2 password from team_config.h, one phone at a time).
// The phone opens http://192.168.4.1 ; the page then talks over ONE WebSocket (port 81) that stays open:
// every touch is sent the moment it happens (no polling), Nagle is off, Wi-Fi power save is off, the loop runs at 100 Hz.
//
// Phone -> robot (one text frame each):  D thr turn  (-100..100, turn > 0 = left)   S speed(0..2)   X (STOP)
//   A 1|0 (arm on/limp)   M mask   Q joint deg (target)   V joint deg_per_s (hold buttons, 0 = stop)   P n (ping)   G (config)
// Robot -> phone:  C{json config}   T bat on speed latch q0..q5   P n (pong)
//
// Safety: the phone sends at least every 50 ms. Nothing for 300 ms -> wheels stop, hold buttons stop, the arm stays
// where it is with PWM on (the gripper keeps its grip). STOP latches the wheels until the stick is centred.
// Every joint starts limp; switching a joint on makes it go to its target at once. Angles are clamped to the
// calibrated safe ends; joints not marked done in the calibrator can't be switched on. The KCD4 kill switch cuts power.
// Calibration: the browser calibrator (docs/calibrator) works over USB with this same firmware (serial commands below).
#include <Arduino.h>
#include <WiFi.h>
#include <WebServer.h>
#include <Wire.h>
#include <Preferences.h>
#include <SHA1Builder.h>
#include <base64.h>
#include <esp_wifi.h>
#include <ThenarLink.h>
#include <tw_armcal.h>

#ifdef TW_EXAMPLE_CREDENTIALS
#warning "Example credentials in use: run  python firmware/tools/new_key.py \"Thenar Walker\"  first"
#endif

// ----------------------------------------------------------------- pins (ESP32-S3 board)
int sdaPin = 8, sclPin = 9, oePin = 10;          // overridden by the calibrator's PINS setting (NVS "tw-armpins")
constexpr int PWM_PIN[2] = {4, 6};               // MDD10A PWM1 (left side), PWM2 (right side)
constexpr int DIR_PIN[2] = {5, 7};               // MDD10A DIR1, DIR2
constexpr int SIDE_SIGN[2] = {1, -1};            // right-side motors face the other way
constexpr int BATT_PIN = 1, LED_PIN = 2;
constexpr float BATT_DIVIDER = (100.0f + 27.0f) / 27.0f;   // 100k / 27k divider
constexpr int PWM_HZ = 20000, PWM_BITS = 10;
constexpr uint8_t PCA = 0x40;
constexpr float PCA_CLOCK_HZ = 25000000;         // same constant as the calibrator, so calibrated pulses match

constexpr uint32_t LINK_TIMEOUT_MS = 300;
constexpr uint32_t TICK_MS = 10;                 // 100 Hz control loop
constexpr uint32_t TELE_MS = 100;                // status to the phone
constexpr float ARM_DPS = 120;                   // slew limit toward a slider target
constexpr float VEL_MAX = 90;                    // hold-button speed cap

WebServer http(80);
WiFiServer wsServer(81);
WiFiClient ws;
bool wsOpen = false;
uint8_t rx[192];
size_t rxLen = 0;

tw::ArmCal cal;
bool calOk = false, pcaOk = false, linkUp = false, stopLatch = false;
uint8_t prescale = 121;
int speed = 1;                                   // 0 slow, 1 mid, 2 fast (tw::SPEED_SCALE)
float lo[6], hi[6], goal[6], cur[6], vel[6];
bool on[6], raw[6];                              // raw: driven by the calibrator in plain microseconds
float rawCur[6], rawTgt[6], rawRate = 300;
float thr = 0, trn = 0, wheelT[2] = {0, 0}, wheel[2] = {0, 0};
uint32_t lastMsg = 0, lastTick = 0, lastTele = 0;
char ssid[32];

// ----------------------------------------------------------------- hardware
bool reg(uint8_t r, uint8_t v) { Wire.beginTransmission(PCA); Wire.write(r); Wire.write(v); return Wire.endTransmission() == 0; }

void chanOff(int ch) {   // full-off bit: no pulse, the servo goes limp
  Wire.beginTransmission(PCA); Wire.write(uint8_t(6 + 4 * ch)); Wire.write(0); Wire.write(0); Wire.write(0); Wire.write(0x10);
  Wire.endTransmission();
}

void chanPulse(int ch, float us) {
  uint16_t count = lroundf(us * PCA_CLOCK_HZ / (1e6f * (prescale + 1)));
  Wire.beginTransmission(PCA); Wire.write(uint8_t(6 + 4 * ch)); Wire.write(0); Wire.write(0);
  Wire.write(count & 0xFF); Wire.write((count >> 8) & 0x0F);
  Wire.endTransmission();
}

void servoWrite(int ch, float q) {
  float us = tw::armcal_pulse(cal, ch, q);
  if (!tw::armcal_pulse_ok(cal, ch, us)) { chanOff(ch); on[ch] = false; return; }   // never outside the safe ends
  chanPulse(ch, us);
}

void updateOe() {
  bool any = false;
  for (int i = 0; i < 6; i++) any |= on[i] || raw[i];
  digitalWrite(oePin, any ? LOW : HIGH);
}

void motorWrite(int side, float v) {   // side 0 = left, 1 = right; v in -1..1
  v = tw::clampf(v * SIDE_SIGN[side], -1, 1);
  digitalWrite(DIR_PIN[side], v < 0 ? HIGH : LOW);
  ledcWrite(PWM_PIN[side], lroundf(fabsf(v) * ((1 << PWM_BITS) - 1)));
}

float batteryV() { return analogReadMilliVolts(BATT_PIN) * BATT_DIVIDER / 1000.0f; }

// ----------------------------------------------------------------- control
void setDrive(float t, float r) {   // same mixing as tw::Robot (turn > 0 = left)
  t = tw::clampf(t, -1, 1); r = tw::clampf(r, -1, 1);
  if (fabsf(t) < tw::DRIVE_DEADBAND) t = 0;
  if (fabsf(r) < tw::DRIVE_DEADBAND) r = 0;
  if (t == 0 && r != 0) {          // spin in place: breakaway floor + turn scale
    float mag = tw::SPIN_MIN + (tw::TURN_SCALE[speed] - tw::SPIN_MIN) * fabsf(r);
    wheelT[0] = r > 0 ? -mag : mag;
    wheelT[1] = -wheelT[0];
  } else {
    float l = t * tw::SPEED_SCALE[speed] - r * tw::TURN_SCALE[speed], rr = t * tw::SPEED_SCALE[speed] + r * tw::TURN_SCALE[speed];
    float m = fmaxf(1.0f, fmaxf(fabsf(l), fabsf(rr)));
    wheelT[0] = l / m; wheelT[1] = rr / m;
  }
}

void freezeArm() { for (int i = 0; i < 6; i++) { goal[i] = cur[i]; vel[i] = 0; } }

void stopAll() {   // STOP: wheels stop now and stay stopped until the stick is centred; arm holds where it is
  wheelT[0] = wheelT[1] = wheel[0] = wheel[1] = 0;
  stopLatch = true;
  freezeArm();
}

void applyCal() {   // angle range of every joint = its calibrated safe ends
  for (int i = 0; i < 6; i++) {
    float a = (cal.min_us[i] - cal.zero_us[i]) / (cal.us_per_deg[i] * cal.sign[i]);
    float b = (cal.max_us[i] - cal.zero_us[i]) / (cal.us_per_deg[i] * cal.sign[i]);
    lo[i] = fminf(a, b); hi[i] = fmaxf(a, b);
    goal[i] = cur[i] = tw::clampf(0, lo[i], hi[i]);
    vel[i] = 0;
  }
}

bool jointUsable(int i) { return calOk && ((cal.done_mask >> i) & 1) && lo[i] < hi[i]; }

int usableMask() {
  int m = 0;
  for (int i = 0; i < 6; i++) m |= jointUsable(i) << i;
  return m;
}

int onMask() {
  int m = 0;
  for (int i = 0; i < 6; i++) m |= on[i] << i;
  return m;
}

void setJoint(int i, bool want) {
  want = want && pcaOk && jointUsable(i);
  if (want && !on[i]) { raw[i] = false; vel[i] = 0; cur[i] = goal[i]; on[i] = true; servoWrite(i, cur[i]); }   // jumps to the target
  else if (!want && on[i]) { on[i] = false; vel[i] = 0; chanOff(i); }
}

void setMask(int m) {
  for (int i = 0; i < 6; i++) setJoint(i, (m >> i) & 1);
  updateOe();
}

void allLimp() {
  for (int i = 0; i < 6; i++) { on[i] = raw[i] = false; vel[i] = 0; if (pcaOk) chanOff(i); }
  updateOe();
}

// ----------------------------------------------------------------- WebSocket (RFC 6455, one phone, small text frames)
void wsClose() {
  if (ws) ws.stop();
  wsOpen = false;
  rxLen = 0;
}

void wsSend(const char *s, size_t n) {
  if (!wsOpen) return;
  uint8_t buf[700];
  size_t h = 2;
  if (n + 4 > sizeof buf) return;
  buf[0] = 0x81;                                   // FIN + text
  if (n < 126) buf[1] = n;
  else { buf[1] = 126; buf[2] = n >> 8; buf[3] = n & 0xFF; h = 4; }
  memcpy(buf + h, s, n);
  if (ws.write(buf, h + n) != h + n) wsClose();   // one write per frame -> one TCP segment, sent at once (no Nagle)
}

void sendCfg() {
  char b[640];
  int n = snprintf(b, sizeof b, "C{\"ssid\":\"%s\",\"cal\":%d,\"pca\":%d,\"usable\":%d,\"on\":%d,\"sp\":%d,\"lo\":[", ssid,
                   calOk ? 1 : 0, pcaOk ? 1 : 0, usableMask(), onMask(), speed);
  for (int i = 0; i < 6; i++) n += snprintf(b + n, sizeof b - n, "%s%.1f", i ? "," : "", lo[i]);
  n += snprintf(b + n, sizeof b - n, "],\"hi\":[");
  for (int i = 0; i < 6; i++) n += snprintf(b + n, sizeof b - n, "%s%.1f", i ? "," : "", hi[i]);
  n += snprintf(b + n, sizeof b - n, "],\"g\":[");
  for (int i = 0; i < 6; i++) n += snprintf(b + n, sizeof b - n, "%s%.1f", i ? "," : "", goal[i]);
  n += snprintf(b + n, sizeof b - n, "]}");
  wsSend(b, n);
}

void sendTele() {
  char b[160];
  int n = snprintf(b, sizeof b, "T %.2f %d %d %d", batteryV(), onMask(), speed, stopLatch ? 1 : 0);
  for (int i = 0; i < 6; i++) n += snprintf(b + n, sizeof b - n, " %.1f", cur[i]);
  wsSend(b, n);
}

// finds "name:" (case-insensitive) in an HTTP header block and copies its value
bool headerValue(const char *req, const char *name, char *out, size_t cap) {
  size_t nl = strlen(name);
  for (const char *p = req; *p; p++) {
    if ((p == req || p[-1] == '\n') && !strncasecmp(p, name, nl) && p[nl] == ':') {
      p += nl + 1;
      while (*p == ' ') p++;
      size_t k = 0;
      while (*p && *p != '\r' && *p != '\n' && k + 1 < cap) out[k++] = *p++;
      out[k] = 0;
      return k > 0;
    }
  }
  return false;
}

void wsAccept() {
  WiFiClient c = wsServer.accept();
  if (!c) return;
  char req[1024];
  size_t n = 0;
  uint32_t t0 = millis();
  while (millis() - t0 < 400 && n < sizeof req - 1) {   // the upgrade request arrives in one go
    int a = c.available();
    if (a > 0) {
      int r = c.read((uint8_t *)req + n, min((size_t)a, sizeof req - 1 - n));
      if (r > 0) n += r;
      req[n] = 0;
      if (strstr(req, "\r\n\r\n")) break;
    } else {
      delay(1);
    }
  }
  req[n] = 0;
  char key[64];
  if (!headerValue(req, "Sec-WebSocket-Key", key, sizeof key)) { c.stop(); return; }
  String k = String(key) + "258EAFA5-E914-47DA-95CA-C5AB0DC85B11";
  SHA1Builder sha;
  sha.begin();
  sha.add((const uint8_t *)k.c_str(), k.length());
  sha.calculate();
  uint8_t digest[20];
  sha.getBytes(digest);
  String resp = "HTTP/1.1 101 Switching Protocols\r\nUpgrade: websocket\r\nConnection: Upgrade\r\nSec-WebSocket-Accept: " +
                base64::encode(digest, 20) + "\r\n\r\n";
  if (wsOpen) wsClose();                           // the newest connection wins (the AP allows one phone anyway)
  ws = c;
  ws.setNoDelay(true);
  ws.write((const uint8_t *)resp.c_str(), resp.length());
  wsOpen = true;
  rxLen = 0;
  lastMsg = millis();
  linkUp = true;
  Serial.println("phone connected");
  sendCfg();
}

void handleCmd(char *c) {
  int i, v;
  float f;
  switch (c[0]) {
    case 'D': {
      int a = 0, b = 0;
      if (sscanf(c + 1, "%d %d", &a, &b) == 2) { thr = a / 100.0f; trn = b / 100.0f; }
      break;
    }
    case 'S': if (sscanf(c + 1, "%d", &v) == 1) speed = constrain(v, 0, 2); break;
    case 'X': stopAll(); break;
    case 'A': if (sscanf(c + 1, "%d", &v) == 1) setMask(v ? usableMask() : 0); break;
    case 'M': if (sscanf(c + 1, "%d", &v) == 1) setMask(v); break;
    case 'Q':
      if (sscanf(c + 1, "%d %f", &i, &f) == 2 && i >= 0 && i < 6 && isfinite(f)) { goal[i] = tw::clampf(f, lo[i], hi[i]); vel[i] = 0; }
      break;
    case 'V':
      if (sscanf(c + 1, "%d %f", &i, &f) == 2 && i >= 0 && i < 6 && isfinite(f)) vel[i] = tw::clampf(f, -VEL_MAX, VEL_MAX);
      break;
    case 'P': wsSend(c, strlen(c)); break;         // ping: echo straight back so the phone can show the round trip
    case 'G': sendCfg(); break;
  }
}

void wsPoll() {
  if (!wsOpen) return;
  if (!ws.connected()) { Serial.println("phone disconnected"); wsClose(); return; }
  int a;
  while ((a = ws.available()) > 0 && rxLen < sizeof rx) {
    int r = ws.read(rx + rxLen, min((size_t)a, sizeof rx - rxLen));
    if (r <= 0) break;
    rxLen += r;
  }
  while (rxLen >= 2) {                             // every complete frame in the buffer
    uint8_t op = rx[0] & 0x0F;
    size_t len = rx[1] & 0x7F, h = 2;
    if (!(rx[1] & 0x80) || len > 125) { wsClose(); return; }   // browsers always mask; our messages are short
    if (rxLen < h + 4 + len) return;
    uint8_t *mask = rx + h, *p = rx + h + 4;
    for (size_t j = 0; j < len; j++) p[j] ^= mask[j & 3];
    if (op == 1) {
      char cmd[128];
      memcpy(cmd, p, len);
      cmd[len] = 0;
      lastMsg = millis();
      if (!linkUp) { linkUp = true; Serial.println("phone link back"); }
      handleCmd(cmd);
    } else if (op == 8) {
      wsClose();
      return;
    } else if (op == 9) {                          // ping -> pong with the same payload
      uint8_t pong[130] = {0x8A, (uint8_t)len};
      memcpy(pong + 2, p, len);
      ws.write(pong, len + 2);
    }
    size_t used = h + 4 + len;
    memmove(rx, rx + used, rxLen - used);
    rxLen -= used;
  }
}

// ----------------------------------------------------------------- serial: the browser calibrator (docs/calibrator)
char sline[96];
size_t sused = 0;
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
void loop() {
  http.handleClient();
  wsAccept();
  wsPoll();
  serialPoll();
  uint32_t now = millis();
  if (uint32_t(now - lastTick) < TICK_MS) return;
  float dt = (now - lastTick) / 1000.0f;
  if (dt > 0.1f) dt = 0.1f;
  lastTick = now;

  if (linkUp && uint32_t(now - lastMsg) > LINK_TIMEOUT_MS) {   // phone silent: stop wheels, hold the arm
    linkUp = false;
    thr = trn = 0;
    freezeArm();
    Serial.println("phone silent -> wheels stopped, arm holding");
  }

  bool centred = fabsf(thr) < tw::DRIVE_DEADBAND && fabsf(trn) < tw::DRIVE_DEADBAND;
  if (stopLatch && centred) stopLatch = false;
  setDrive(stopLatch ? 0 : thr, stopLatch ? 0 : trn);
  float a = tw::DRIVE_ACCEL_PER_S * dt;
  for (int k = 0; k < 2; k++) {
    float t = wheelT[k], w = wheel[k];
    if (t * w < 0) w = 0;                          // reversing: stop first
    else if (fabsf(t) <= fabsf(w)) w = t;          // slowing / stopping: immediate
    else w += tw::clampf(t - w, -a, a);            // speeding up: ramped
    wheel[k] = w;
    motorWrite(k, w);
  }

  float step = ARM_DPS * dt;
  for (int i = 0; i < 6; i++) {
    if (!on[i]) continue;
    if (vel[i] != 0) goal[i] = tw::clampf(goal[i] + vel[i] * dt, lo[i], hi[i]);
    if (cur[i] == goal[i]) continue;
    cur[i] += tw::clampf(goal[i] - cur[i], -step, step);
    servoWrite(i, cur[i]);
  }
  float rstep = rawRate * dt;
  for (int i = 0; i < 6; i++) {
    if (!raw[i] || rawCur[i] == rawTgt[i]) continue;
    rawCur[i] += tw::clampf(rawTgt[i] - rawCur[i], -rstep, rstep);
    chanPulse(i, rawCur[i]);
  }
  updateOe();
  digitalWrite(LED_PIN, linkUp ? HIGH : ((now / 250) & 1));
  if (wsOpen && uint32_t(now - lastTele) >= TELE_MS) { lastTele = now; sendTele(); }
}

// ----------------------------------------------------------------- the phone page
const char PAGE[] PROGMEM = R"HTML(<!doctype html>
<html lang="en"><head><meta charset="utf-8">
<meta name="viewport" content="width=device-width,initial-scale=1,maximum-scale=1,user-scalable=no,viewport-fit=cover">
<meta name="theme-color" content="#0e1318">
<title>Thenar Walker</title>
<style>
:root{--bg:#0e1318;--card:#161d25;--card2:#1d2630;--line:#2b3744;--fg:#e9eef3;--dim:#8f9eae;--acc:#f2913d;--ok:#45d184;--bad:#ff5b52;--warn:#ffc15e}
*{box-sizing:border-box;-webkit-tap-highlight-color:transparent;-webkit-touch-callout:none;-webkit-user-select:none;user-select:none}
html,body{height:100%;margin:0;background:var(--bg);color:var(--fg);font:14px/1.35 system-ui,-apple-system,"Segoe UI",Roboto,sans-serif;overscroll-behavior:none}
body{display:flex;flex-direction:column;padding:env(safe-area-inset-top) max(10px,env(safe-area-inset-right)) env(safe-area-inset-bottom) max(10px,env(safe-area-inset-left))}
.bar{display:flex;align-items:center;gap:6px;flex-wrap:wrap;padding:8px 0}
.bar b{font-size:15px;letter-spacing:.06em;margin-right:auto}
.pill{font:600 12px ui-monospace,Consolas,monospace;padding:4px 9px;border-radius:99px;background:var(--card2);color:var(--dim);white-space:nowrap}
.pill.ok{background:var(--ok);color:#06140c}.pill.bad{background:var(--bad);color:#fff}.pill.warn{background:var(--warn);color:#1d1300}
button{font:600 14px system-ui,sans-serif;color:var(--fg);background:var(--card2);border:1px solid var(--line);border-radius:10px;padding:9px 12px;touch-action:manipulation}
button:active,button.held{background:var(--acc);color:#1b0d01;border-color:var(--acc)}
button.sel{background:var(--acc);color:#1b0d01;border-color:var(--acc)}
button:disabled{opacity:.35}
#stop{background:var(--bad);border-color:var(--bad);color:#fff;font-size:16px;padding:10px 18px;letter-spacing:.06em}
.main{flex:1;display:grid;grid-template-columns:minmax(0,1fr) minmax(0,1.25fr);gap:10px;min-height:0;padding-bottom:8px}
@media (orientation:portrait){.main{grid-template-columns:minmax(0,1fr)}}
.card{background:var(--card);border:1px solid var(--line);border-radius:14px;padding:10px;min-width:0;display:flex;flex-direction:column;gap:8px}
.card h2{margin:0;font-size:11px;letter-spacing:.14em;color:var(--dim);text-transform:uppercase;display:flex;align-items:center;gap:6px}
.card h2 span{margin-left:auto}
#padWrap{flex:1;display:grid;place-items:center;min-height:220px}
#pad{position:relative;width:min(100%,62vh,330px);aspect-ratio:1;border-radius:50%;background:radial-gradient(circle,#1d2732 0 30%,#141b22 70%);border:2px solid var(--line);touch-action:none}
#pad::before,#pad::after{content:"";position:absolute;background:var(--line);left:50%;top:8%;bottom:8%;width:1px}
#pad::after{top:50%;left:8%;right:8%;height:1px;width:auto;bottom:auto}
#knob{position:absolute;left:50%;top:50%;width:34%;aspect-ratio:1;margin:-17% 0 0 -17%;border-radius:50%;background:var(--acc);box-shadow:0 6px 18px #0009;pointer-events:none;will-change:transform}
.seg{display:flex;gap:4px}.seg button{flex:1;padding:8px 4px}
.joints{display:flex;flex-direction:column;gap:6px;overflow-y:auto;min-height:0}
.j{display:grid;grid-template-columns:76px 52px minmax(0,1fr) 52px 56px;gap:6px;align-items:center}
.j .n{font-weight:700;font-size:13px;line-height:1.15}.j .n small{display:block;font-weight:400;color:var(--dim);font-size:11px}
.j .h{padding:10px 0;font-size:18px;touch-action:none}
.j .v{grid-column:3;text-align:center;font:600 15px ui-monospace,Consolas,monospace}
.j input{grid-column:3;width:100%;margin:0;accent-color:var(--acc);height:28px;touch-action:none}
.j .slot{display:grid;grid-template-rows:auto auto}
.j .t{padding:9px 0}.j .t.on{background:var(--ok);color:#06140c;border-color:var(--ok)}
.row{display:flex;gap:6px;flex-wrap:wrap;align-items:center}
.note{color:var(--dim);font-size:12px}
.warn{color:var(--warn)}
</style></head><body>
<div class="bar">
  <b>THENAR</b>
  <span id="link" class="pill bad">connecting</span>
  <span id="rtt" class="pill">-- ms</span>
  <span id="bat" class="pill">-- V</span>
  <button id="fs">Full screen</button>
  <button id="stop">STOP</button>
</div>
<div class="main">
  <div class="card">
    <h2>Drive <span id="latch" class="pill warn" hidden>STOPPED — centre the stick</span></h2>
    <div id="padWrap"><div id="pad"><div id="knob"></div></div></div>
    <div class="seg" id="speed"><button data-s="0">Slow</button><button data-s="1" class="sel">Mid</button><button data-s="2">Fast</button></div>
  </div>
  <div class="card">
    <h2>Arm <span class="row"><button id="armOn">Arm ON</button><button id="limp">Limp</button><button id="fine">Fine</button></span></h2>
    <div class="joints" id="joints"></div>
    <div class="note" id="calnote"></div>
  </div>
</div>
<script>
const NAMES=[["J1","Base pan"],["J2","Shoulder"],["J3","Elbow"],["J4","Wrist flex"],["J5","Wrist roll"],["J6","Gripper"]];
const $=id=>document.getElementById(id);
let ws=null,open=false,cfg=null,mask=0,sp=1,fine=false,thr=0,trn=0,lastD="",dirty=false,drag=-1,pingT=0;
const q=[0,0,0,0,0,0],qSend=[null,null,null,null,null,null];
function send(s){if(open&&ws.readyState===1)ws.send(s)}
function connect(){
  ws=new WebSocket("ws://"+(location.hostname||"192.168.4.1")+":81/");
  ws.onopen=()=>{open=true;$("link").textContent="linked";$("link").className="pill ok";send("G");sendDrive(true)};
  ws.onclose=()=>{open=false;$("link").textContent="NO LINK";$("link").className="pill bad";$("rtt").textContent="-- ms";setTimeout(connect,300)};
  ws.onerror=()=>{try{ws.close()}catch(e){}};
  ws.onmessage=e=>onMsg(e.data);
}
function onMsg(m){
  const k=m[0];
  if(k==="T"){const a=m.split(" ");const bat=+a[1];mask=+a[2];sp=+a[3];$("latch").hidden=a[4]!=="1";
    $("bat").textContent=bat>1?bat.toFixed(1)+" V":"-- V";for(let i=0;i<6;i++){q[i]=+a[5+i];}showJoints();showSpeed();}
  else if(k==="P"){const t=+m.slice(2);const r=performance.now()-t;$("rtt").textContent=r.toFixed(0)+" ms";$("rtt").className="pill"+(r<30?" ok":r<80?" warn":" bad")}
  else if(k==="C"){cfg=JSON.parse(m.slice(1));mask=cfg.on;sp=cfg.sp;for(let i=0;i<6;i++)q[i]=cfg.g[i];build();showSpeed()}
}
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

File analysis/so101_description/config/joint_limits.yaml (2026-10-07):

status: Source software limits, not physical travel certification; table collisions
  documented
joint_limits:
  shoulder_pan:
    has_position_limits: true
    min_position: -1.4835298641951802
    max_position: 1.4835298641951802
    has_velocity_limits: true
    max_velocity: 0.17453292519943295
    has_effort_limits: false
    max_effort: null
  shoulder_lift:
    has_position_limits: true
    min_position: -1.3962634015954636
    max_position: 1.3962634015954636
    has_velocity_limits: true
    max_velocity: 0.17453292519943295
    has_effort_limits: false
    max_effort: null
  elbow_flex:
    has_position_limits: true
    min_position: -1.3962634015954636
    max_position: 1.3962634015954636
    has_velocity_limits: true
    max_velocity: 0.17453292519943295
    has_effort_limits: false
    max_effort: null
  wrist_flex:
    has_position_limits: true
    min_position: -1.3962634015954636
    max_position: 1.3962634015954636
    has_velocity_limits: true
    max_velocity: 0.17453292519943295
    has_effort_limits: false
    max_effort: null
  wrist_roll:
    has_position_limits: true
    min_position: -1.4835298641951802
    max_position: 1.4835298641951802
    has_velocity_limits: true
    max_velocity: 0.17453292519943295
    has_effort_limits: false
    max_effort: null
  gripper:
    has_position_limits: true
    min_position: 0.0
    max_position: 1.2217304763960306
    has_velocity_limits: true
    max_velocity: 0.17453292519943295
    has_effort_limits: false
    max_effort: null

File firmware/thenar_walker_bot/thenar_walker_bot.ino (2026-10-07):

// Thenar Walker — robot ESP32 (on the bot).
// Wi-Fi access point "<TeamName>_TF" (WPA2, one station max), authenticated UDP commands,
// 4 x JGA25-370 12 V motors on 1 x Cytron MDD10A (2 per channel), 6 x MG996R arm servos on a PCA9685.
// Safety: see ThenarLink/tw_robot.h — link loss stops the wheels and freezes the arm with
// servo PWM still on (gripper keeps holding); the hardware kill switch cuts all power.
#include <Arduino.h>
#include <WiFi.h>
#include <WiFiUdp.h>
#include <Wire.h>
#include <ThenarLink.h>
#include "calibration.h"

#ifdef TW_EXAMPLE_CREDENTIALS
#warning "Example credentials in use: copy ThenarLink/src/team_config.example.h to team_config.h"
#endif

// ----------------------------------------------------------------- pins (see docs/WIRING.md)
constexpr int SDA_PIN = 21, SCL_PIN = 22, PCA_OE_PIN = 13, LED_PIN = 2, BATT_PIN = 34;
// Cytron MDD10A Rev2.0, sign-magnitude: PWM pin = speed, DIR pin = direction; PWM low = brake.
// Channel 1 = left side (FL + RL wired in parallel), channel 2 = right side (FR + RR in parallel).
constexpr int PWM_PIN[2] = {25, 16};          // MDD10A PWM1, PWM2
constexpr int DIR_PIN[2] = {26, 17};          // MDD10A DIR1, DIR2
constexpr int SIDE_SIGN[2] = {1, -1};         // right-side motors face the other way
constexpr int PWM_HZ = 20000, PWM_BITS = 10;
constexpr float BATT_DIVIDER = (100.0f + 27.0f) / 27.0f;   // 100k / 27k divider to GPIO34
constexpr uint8_t PCA_ADDR = 0x40;

WiFiUDP udp;
tw::Robot robot;
tw::CmdGate gate;
IPAddress ctrlIp;
uint16_t ctrlPort = 0;
uint32_t lastTick = 0, lastStatus = 0;
uint8_t prescale = 0;
bool pcaOk = false;
char ssid[32];

bool pcaWrite(uint8_t reg, uint8_t v) {
  Wire.beginTransmission(PCA_ADDR); Wire.write(reg); Wire.write(v);
  return Wire.endTransmission() == 0;
}

bool servoWrite(int ch, float q) {
  float us = SERVO_ZERO_US[ch] + q * US_PER_DEGREE[ch] * SERVO_SIGN[ch];
  if (!(us >= PULSE_MIN_US[ch] && us <= PULSE_MAX_US[ch])) return false;
  uint16_t count = lroundf(us * PCA_CLOCK_HZ / (1e6f * (prescale + 1)));
  Wire.beginTransmission(PCA_ADDR);
  Wire.write(uint8_t(6 + 4 * ch)); Wire.write(0); Wire.write(0);
  Wire.write(count & 0xFF); Wire.write(count >> 8);
  return Wire.endTransmission() == 0;
}

void motorWrite(int side, float v) {   // side 0 = left, 1 = right; v in -1..1
  v = tw::clampf(v * SIDE_SIGN[side], -1, 1);
  digitalWrite(DIR_PIN[side], v < 0 ? HIGH : LOW);
  ledcWrite(PWM_PIN[side], lroundf(fabsf(v) * ((1 << PWM_BITS) - 1)));
}

uint16_t batteryMv() {
  return uint16_t(analogReadMilliVolts(BATT_PIN) * BATT_DIVIDER);
}

void handlePacket() {
  int n = udp.parsePacket();
  if (n <= 0) return;
  uint8_t buf[64];
  if (n > int(sizeof buf)) { udp.clear(); return; }
  udp.read(buf, n);
  tw::Hello h;
  if (tw::parse(buf, n, tw::MAGIC_HELLO, team::LINK_KEY, h)) {
    // authenticated controller (re)pairs: fresh random session invalidates any old packets
    uint32_t session = esp_random() | 1;
    gate.new_session(session);
    ctrlIp = udp.remoteIP(); ctrlPort = udp.remotePort();
    tw::Welcome w{tw::MAGIC_WELCOME, h.ctrl_nonce, session, {0}};
    tw::sign(w, team::LINK_KEY);
    udp.beginPacket(ctrlIp, ctrlPort); udp.write((uint8_t *)&w, sizeof w); udp.endPacket();
    Serial.printf("PAIRED %s:%u session %08lx\n", ctrlIp.toString().c_str(), ctrlPort, (unsigned long)session);
    return;
  }
  tw::Cmd c;
  if (udp.remoteIP() != ctrlIp || udp.remotePort() != ctrlPort) return;   // not our controller
  if (gate.accept(buf, n, team::LINK_KEY, c)) robot.on_command(millis(), c);
}

void setup() {
  pinMode(PCA_OE_PIN, OUTPUT); digitalWrite(PCA_OE_PIN, HIGH);   // servo outputs off until engaged
  pinMode(LED_PIN, OUTPUT);
  for (int k = 0; k < 2; k++) {
    pinMode(DIR_PIN[k], OUTPUT); digitalWrite(DIR_PIN[k], LOW);
    ledcAttach(PWM_PIN[k], PWM_HZ, PWM_BITS); ledcWrite(PWM_PIN[k], 0);
  }
  analogSetPinAttenuation(BATT_PIN, ADC_11db);
  Serial.begin(115200);
  Wire.begin(SDA_PIN, SCL_PIN); Wire.setClock(400000); Wire.setTimeOut(20);
  prescale = uint8_t(lroundf(PCA_CLOCK_HZ / (4096.0f * 50)) - 1);
  pcaOk = pcaWrite(0, 0x10) && pcaWrite(0xFE, prescale) && pcaWrite(1, 4) && pcaWrite(0, 0x20);
  tw::device_name(team::TEAM_NAME, ssid, sizeof ssid);
  WiFi.mode(WIFI_AP);
  WiFi.softAP(ssid, team::WIFI_PASSWORD, 6, 0, 1);   // channel 6, visible, max 1 station
  udp.begin(tw::UDP_PORT);
  Serial.printf("THENAR WALKER BOT  AP %s  %s  PCA9685 %s  servo calibration %s\n", ssid,
                WiFi.softAPIP().toString().c_str(), pcaOk ? "ok" : "MISSING", FOLLOWER_CALIBRATED ? "ok" : "PENDING (arm stays off)");
}

void loop() {
  handlePacket();
  uint32_t now = millis();
  if (uint32_t(now - lastTick) < 10) return;     // 100 Hz control loop
  lastTick = now;
  tw::Outputs o = robot.tick(now);
  for (int k = 0; k < 2; k++) motorWrite(k, o.wheel[k]);
  bool armOk = o.servo_pwm_on && pcaOk && FOLLOWER_CALIBRATED;
  if (armOk) {
    for (int i = 0; i < 6; i++)
      if (!servoWrite(i, o.q[i])) { armOk = false; break; }
  }
  // PWM stays on through HOLD so the gripper keeps its grip; only a bus/pulse fault turns it off
  digitalWrite(PCA_OE_PIN, armOk ? LOW : HIGH);
  digitalWrite(LED_PIN, robot.state == tw::ACTIVE ? HIGH : ((now / 250) & 1));
  if (ctrlPort && uint32_t(now - lastStatus) >= 100) {
    lastStatus = now;
    tw::Status s{tw::MAGIC_STATUS, gate.session, gate.last_seq, robot.state, robot.reason, batteryMv(), {0}};
    tw::sign(s, team::LINK_KEY);
    udp.beginPacket(ctrlIp, ctrlPort); udp.write((uint8_t *)&s, sizeof s); udp.endPacket();
  }
}

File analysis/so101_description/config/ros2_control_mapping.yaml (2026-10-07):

status: Mapping only; no hardware plugin or control deployment provided
joints:
  shoulder_pan:
    pca9685_channel: 0
    command_interface: position
    feedback: UNAVAILABLE from ordinary MG996R three-wire interface
    sign_default: 1
    zero_us: 1500
    us_per_degree: 5.555556
    mechanical_reduction: 1
    physical_calibration: UNVERIFIED
  shoulder_lift:
    pca9685_channel: 1
    command_interface: position
    feedback: UNAVAILABLE from ordinary MG996R three-wire interface
    sign_default: 1
    zero_us: 1500
    us_per_degree: 5.555556
    mechanical_reduction: 1
    physical_calibration: UNVERIFIED
  elbow_flex:
    pca9685_channel: 2
    command_interface: position
    feedback: UNAVAILABLE from ordinary MG996R three-wire interface
    sign_default: 1
    zero_us: 1500
    us_per_degree: 5.555556
    mechanical_reduction: 1
    physical_calibration: UNVERIFIED
  wrist_flex:
    pca9685_channel: 3
    command_interface: position
    feedback: UNAVAILABLE from ordinary MG996R three-wire interface
    sign_default: 1
    zero_us: 1500
    us_per_degree: 5.555556
    mechanical_reduction: 1
    physical_calibration: UNVERIFIED
  wrist_roll:
    pca9685_channel: 4
    command_interface: position
    feedback: UNAVAILABLE from ordinary MG996R three-wire interface
    sign_default: 1
    zero_us: 1500
    us_per_degree: 5.555556
    mechanical_reduction: 1
    physical_calibration: UNVERIFIED
  gripper:
    pca9685_channel: 5
    command_interface: position
    feedback: UNAVAILABLE from ordinary MG996R three-wire interface
    sign_default: 1
    zero_us: 1500
    us_per_degree: 5.555556
    mechanical_reduction: 1
    physical_calibration: UNVERIFIED

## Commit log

2026-10-07 Thenar Walker: RoboReach 2026-27 rover for the thenar-arms follower
    SolidWorks CAD and rule checks, MuJoCo course simulation, ESP32 firmware
    (MDD10A PWM+DIR), print plates for the P1S/SparkX, tub v2 for the 370
    plastic-gearbox motors with engraved logos, wooden deck template, build book
    and the HyperFrames assembly film project.
    [Base_MG996R_R3.STL, Base_MG996R_R3.stl, Base_MG996R_R3_body0.stl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]
2026-10-07 README: link the assembly film release
2026-10-07 Add the team's KCD4 kill switch as a detailed model (frame, rocker, clips, 4 tabs)
    cad/tools/make_kill_switch.py -> cad/stl/P-08_Kill_Switch_KCD4.STL; placed in the
    assembly GLB on the wooden deck (22.2 x 30.2 cut-out) and in the assembly film.
    [P-08_Kill_Switch_KCD4.STL]
2026-10-07 Add a small browser STL viewer for the part files
2026-10-08 Arm calibrator: Web Serial app + ESP32-S3 calibration bridge firmware
    docs/calibrator/index.html calibrates each MG996R joint from two easy-to-see
    reference poses (zero, direction, us/deg), records safe ends, tests, and saves
    the result to the robot's NVS (tw_armcal.h) or as calibration.h.
    firmware/arm_calibration: PCA9685 bridge (slew-limited, limp at start, 500-2500 us
    clamp, invalid calibration refused). Verified on the board: PCA9685 at 0x40 on
    SDA 8 / SCL 9 / OE 10, NVS round trip across a reboot.
    [arm_calibration.ino]
2026-10-08 Calibrator launcher: simpler cd, keep the window open on errors
2026-10-08 Phone control: ESP32-S3 Wi-Fi AP + web page (drive joystick, calibrated arm sliders, failsafe)
    [thenar_phone.ino]
2026-10-09 Gamepad control: Bluepad32 pad on the robot (BLE) or a pad paired to the phone (Gamepad API)
    Phone page now only sends arm targets when the phone changes them, so both sources can share the arm;
    STOP latches the wheels until every stick is centred; the robot remembers its first pad.
2026-10-09 Wood deck: cut plan on the 365 x 240 board (2 saw cuts)
2026-10-09 All-wood chassis: cut plan, marks and 1:1 templates for the 365 x 240 board (replaces the printed tub)
    Deck on two 250 x 50 side walls (M8 motor collars through the walls + glued pads), 110 x 132 floor
    between the motors, 8 L-clamps with M3 screws.
2026-10-09 Bracket deck: one 250 x 138 board, motors on L-brackets underneath, fits the 300 x 200 start box (290 x 198)
2026-10-09 Thenar Remote: Expo Android app for drive, arm and Bluetooth game controller
    - native module (Kotlin): reads any controller paired to the phone, binds the app to the
    robot's no-internet Wi-Fi (optionally joins it by SSID/password)
    - same protocol and controller layout as firmware/thenar_phone; robot state is the truth
    - test/mock_robot.py follows the firmware rules; npm test runs 13 end-to-end checks
    - firmware: STOP latch no longer clears itself when the stick is still pushed; CORS header
    [thenar_phone.ino]
2026-10-09 Ground clearance side view (shaft 70, gearbox 51.25, tub 57)
2026-10-10 Thenar Pad Check: browser controller tester with live SVG pad and 3D rover + arm
    Same control rules as the robot (drive mixing, ramp, STOP latch, holds, arm speeds and limits);
    keyboard fallback; raw axes/buttons readout with drift band; standalone index.html built from tester.html.
2026-10-10 Pad Check: no demo motion — nothing moves until a controller or the keyboard does
2026-10-10 thenar_phone: log gamepad presses, START/SELECT and arm state on serial for bring-up
2026-10-10 thenar_phone speaks the calibrator's serial protocol (HELLO/P/REL/OFF/RATE/STATE/CAL/CALSAVE/CALGET)
    One firmware for phone, Xbox (BLE) and calibration; CALSAVE applies the new limits at once, every joint limp.
2026-10-10 Arm calibration from the calibrator session (all 6 joints), same numbers as saved on the robot
2026-10-10 Pad Check drives the real robot: PC controller -> robot Wi-Fi HTTP API (same protocol as the phone app)
    For controllers the ESP32-S3 can't pair (no BLE), e.g. EvoFox One S with its USB receiver.
    Tested against mobile/test/mock_robot.py: link, arm on, drive, STOP latch, speed, unlink -> stop.
2026-10-10 Phone-only, low-latency control: WebSocket (no polling), Nagle off, Wi-Fi power save off, 100 Hz loop
    Drops the gamepad/Bluepad32 and HTTP polling paths. Page: joystick sent on change + 40 ms heartbeat,
    hold-to-move joint buttons (robot integrates the speed), sliders, live round-trip readout.
    300 ms link timeout. Calibrator still works over USB.
2026-10-26 CLAUDE.md project brief + docs/PLAYBOOK.md reusable lessons
    Everything a new Claude session (or a new robot project) needs: rules, robot as built, pins, arm calibration,
    phone WebSocket protocol, repo status map, owner's machine and working style, pitfalls and open items.
2026-10-26 calibrator: Connect Pi (Wi-Fi) speaks the same line protocol to the Raspberry Pi runtime over a WebSocket on port 82; one line handler for both transports
2026-10-26 pi: Raspberry Pi robot runtime thenar_pi, a line-for-line port of thenar_phone.ino (same page, port-81 WebSocket, 300 ms failsafe, STOP latch, limp start, slew, calibrated safe ends, calibrator proto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
2026-10-26 docs: the brain moves to a Raspberry Pi (CLAUDE.md pins, control, repo map, open items), WIRING_PI.md, PLAYBOOK section 2b on porting to the Pi
